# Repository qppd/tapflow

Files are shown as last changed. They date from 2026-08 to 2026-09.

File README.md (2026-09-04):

# TapFlow — RFID-Based Automatic Water and Electrical Line Control with Water Flow Anomaly Detection

> **A Research Project** — Smart water monitoring system that detects leaks and per-room consumption using ESP32 mesh (ESP-NOW), RFID usage tracking, centralized solenoid valve control, and a Next.js web dashboard on Vercel with Firebase Realtime Database + Authentication.

---

## System Overview

```
Room 1 ESP32 ──┐
Room 2 ESP32 ──┼── ESP-NOW ──▶ Main ESP32 ──WiFi──▶ Firebase RTDB
Room 3 ESP32 ──┘            (centralized)              │
     │                      ├── 2× Relay + Solenoid    ▼
     ├── RFID Reader        ├── Calibrated Flow Sensor  Next.js on Vercel
     └── Flow Sensor        │   (GPIO 34)               (Web Dashboard)
       (leak detection)     └── WiFi to Firebase
```

- **3 Room ESP32s** — each has RFID reader (MFRC522) and flow sensor (YF-S201, uncalibrated, leak detection only). Sends readings via ESP-NOW.
- **1 Main ESP32 (centralized)** — receives ESP-NOW data from all rooms, controls 2 solenoid valves via relays, reads calibrated flow sensor (GPIO 34), pushes to Firebase RTDB via WiFi using [mobizt Firebase-ESP-Client](https://github.com/mobizt/Firebase-ESP-Client). Placed before the rooms for centralized control.
- **Firebase** — Realtime Database (data storage) + Authentication (user login)
- **Next.js on Vercel** — web dashboard, real-time monitoring, leak alerts, usage logging per person

---

## Developer Quick-Start: Step-by-Step Process

Follow these steps **in order**. Each step links to the detailed guide.

### Phase 1: Prepare (Do First)

| Step | Action | Guide | Est. Time |
|---|---|---|---|
| 1 | **Buy parts** — Order from BOM (Makerlab Electronics on Shopee/Lazada) | [BOM.md](./docs/bom.md) | 1–2 weeks shipping |
| 2 | **Clone project repo** | [setup.md](./docs/setup.md) | 5 min |

> ⚠️ **Do Step 1–2 in parallel.** Hardware shipping takes longest.

---

### Phase 2: Hardware Assembly

| Step | Action | Guide | Est. Time |
|---|---|---|---|
| 3 | **Wire 3× Room ESP32** — Each gets MFRC522 RFID + YF-S201 flow sensor (leak detection) | [block-diagram.md](./docs/block-diagram.md) | 1 hr |
| 4 | **Wire Main ESP32** — 2× relay (solenoid valves) + calibrated flow sensor + WiFi to Firebase | [block-diagram.md](./docs/block-diagram.md) | 1 hr |
| 5 | **Plumbing** — Install sensors in-line with check valves (arrow = flow direction) | [setup.md](./docs/setup.md) | 2–4 hrs |
| 6 | **Enclosure** — Mount ESP32s in IP67 boxes with cable glands | [block-diagram.md](./docs/block-diagram.md) | 1 hr |

---

### Phase 3: ESP32 Firmware

| Step | Action | Guide | Est. Time |
|---|---|---|---|
| 7 | **Install Arduino IDE 2.x** (Windows/macOS/Linux) | [esp32-firmware-complete-guide.md](./docs/esp32-firmware-complete-guide.md) | 15 min |
| 8 | **Add ESP32 board support** — Board Manager URL + install `esp32 by Espressif Systems` | [esp32-firmware-complete-guide.md](./docs/esp32-firmware-complete-guide.md) | 10 min |
| 9 | **Install libraries** — `ArduinoJson` (JSON) + `MFRC522` (RFID) + `Firebase-ESP-Client` by mobizt + ESP-NOW (built-in) | [esp32-firmware-complete-guide.md](./docs/esp32-firmware-complete-guide.md) | 5 min |
| 10 | **Configure `config.h`** — Device ID, room number, sensor pin, PPL calibration, peer MAC | [esp32-firmware-complete-guide.md](./docs/esp32-firmware-complete-guide.md) | 10 min |
| 11 | **Upload room firmware** to all 3 room ESP32s | [esp32-firmware-complete-guide.md](./docs/esp32-firmware-complete-guide.md) | 5 min |
| 12 | **Upload main firmware** to main ESP32 | [esp32-firmware-complete-guide.md](./docs/esp32-firmware-complete-guide.md) | 5 min |
| 13 | **Verify** — Serial Monitor (921600): room ESP32s send data, main ESP32 receives via ESP-NOW | [esp32-firmware-complete-guide.md](./docs/esp32-firmware-complete-guide.md) | 5 min |

---

### Phase 4: Sensor Calibration

| Step | Action | Guide | Est. Time |
|---|---|---|---|
| 14 | **Bucket test each sensor** — 5L measured, calculate PPL, update `config.h` | [esp32-firmware-complete-guide.md](./docs/esp32-firmware-complete-guide.md#sensor-calibration-bucket-test) | 30 min/sensor |

> 🎯 Target: < 3% error per sensor. Uncalibrated sensors = false leaks / missed leaks.

---

### Phase 5: Web Dashboard (Next.js + Firebase)

| Step | Action | Guide | Est. Time |
|---|---|---|---|
| 15 | **Create Firebase project** — Enable RTDB + Authentication | [setup.md](./docs/setup.md) | 10 min |
| 16 | **Configure Main ESP32** — Add Firebase API key + DB URL to `config.h` | [esp32-firmware-complete-guide.md](./docs/esp32-firmware-complete-guide.md) | 5 min |
| 17 | **Deploy Next.js app** — `vercel deploy`, connect to Firebase | [setup.md](./docs/setup.md) | 10 min |
| 18 | **Power on Main ESP32** — Connects to WiFi → Firebase automatically | — | 2 min |

---

## Essential Guides Only (Bookmark These)

| Guide | Purpose |
|---|---|
| [BOM.md](./docs/bom.md) | Parts list with Shopee links, prices |
| [block-diagram.md](./docs/block-diagram.md) | Pinout, wiring, ESP-NOW topology, enclosure layout |
| [setup.md](./docs/setup.md) | Full phased walkthrough (reference) |
| [esp32-firmware-complete-guide.md](./docs/esp32-firmware-complete-guide.md) | **Complete ESP32 firmware** (room + main, ESP-NOW, ArduinoJson, relay control) |
| [troubleshooting.md](./docs/troubleshooting.md) | Serial commands, LED codes, common fixes |
| [anomaly-detection-guide.md](./docs/anomaly-detection-guide.md) | **Anomaly detection** — algorithms, ESP32 modules, Firebase structure |
| [leak-detection-advanced-guide.md](./docs/leak-detection-advanced-guide.md) | **Leak detection** — 6 rules + mass balance + pulse analysis |
| [module-integration-guide.md](./docs/module-integration-guide.md) | **Module integration** — how all ESP32 modules wire together |
| [web-dashboard-alerts-guide.md](./docs/web-dashboard-alerts-guide.md) | **Web dashboard** — Next.js UI for anomaly/leak detection |

---

### Phase 6: Anomaly + Leak Detection System

| Step | Action | Guide | Est. Time |
|---|---|---|---|
| 19 | **Implement anomaly detection** — Rate-of-change, baseline deviation, burst detection on room ESP32s | [anomaly-detection-guide.md](./docs/anomaly-detection-guide.md) | 2 hrs |
| 20 | **Implement leak detection** — 6 core rules + mass balance + post-shutoff verification | [leak-detection-advanced-guide.md](./docs/leak-detection-advanced-guide.md) | 2 hrs |
| 21 | **Integrate modules** — Wire detection modules into ESP32 main loops, ESP-NOW payload, Firebase push | [module-integration-guide.md](./docs/module-integration-guide.md) | 2 hrs |
| 22 | **Build dashboard alerts** — Real-time alert feed, severity badges, threshold config, trend charts | [web-dashboard-alerts-guide.md](./docs/web-dashboard-alerts-guide.md) | 3 hrs |
| 23 | **Validate** — Test all 6 leak rules, anomaly detection, false positive reduction, Firebase sync | All detection guides | 2 hrs |

> **Detection order:** anomaly-detection-guide → leak-detection-advanced-guide → module-integration-guide → web-dashboard-alerts-guide

---

## Hardware Summary

| Component | Qty | Key Spec |
|---|-----|---|
| ESP32 38-pin Dev Module | 4 | 3 room + 1 main, CP2102/CH340 USB-UART |
| ESP32 Expansion Board | 4 | Screw terminals for each ESP32 |
| MFRC522 RFID Reader | 3 | SPI, 1 per room — usage tracking |
| RFID Cards/Tags | 3+ | Mifare Classic 1K — one per user |
| YF-S201 Flow Sensor | 4 | 3 rooms (leak detection, uncalibrated) + 1 main (calibrated) |
| 2CH Relay with Optocoupler | 1 | Main ESP32 controls 2 solenoids |
| 1-ch Relay 10A | 3 | 1 per room — controls solenoid valve |
| Fotek 40A SSR | 3 | 1 per room — controls room power (lights/fan) |
| Solenoid Valve 1/2" | 5 | NC (normally closed), 12V DC, 2 main + 3 room |
| Check Valve 1/2" | 3 | Brass, prevent backflow |
| PPE Pipe + Fittings | 1 set | 1/2" Polypropylene, heat-fused joints |
| 12V 5A PSU + LM2596S buck | 4 | 220V → 12V → 5V, 1 per ESP32 |
| DC Power Jack Adapter | 4 | 5.5×2.1mm, connects PSU to expansion board |
| IP67 ABS Enclosure | 4 | 175×125×75mm, one per ESP32 |

---

## 3D Models

Fusion 360 source files and fixture renders are in the [`models/`](./models/) folder:

| File | Description |
|---|---|
| [`TapFlow.f3d`](./models/TapFlow.f3d) | Fusion 360 source file (editable) |
| [`tapflow_view_1.png`](./models/tapflow_view_1.png) | Fixture view 1 |
| [`tapflow_view_2.png`](./models/tapflow_view_2.png) | Fixture view 2 |
| [`tapflow_view_3.png`](./models/tapflow_view_3.png) | Fixture view 3 |
| [`tapflow_view_4.png`](./models/tapflow_view_4.png) | Fixture view 4 |
| [`tapflow_view_5.png`](./models/tapflow_view_5.png) | Fixture view 5 |
| [`tapflow_view_6.png`](./models/tapflow_view_6.png) | Fixture view 6 |
| [`tapflow_view_7.png`](./models/tapflow_view_7.png) | Fixture view 7 |
| [`tapflow_view_8.png`](./models/tapflow_view_8.png) | Fixture view 8 |

> Open `TapFlow.f3d` in Fusion 360 to modify the enclosure design, add mounting holes, or adjust dimensions for different components.

---

## Quick Verification Checklist

After each phase, verify:

- [ ] **Phase 1:** All parts received, repo cloned
- [ ] **Phase 2:** All 3 room ESP32s powered, RFID reads cards, sensors pulse; main ESP32 triggers solenoids via relay
- [ ] **Phase 3:** ESP-NOW link working — room data + RFID tags appear on main ESP32 Serial Monitor
- [ ] **Phase 4:** 5L bucket test → < 3% error on each sensor
- [ ] **Phase 5:** Main ESP32 connected to WiFi, data visible in Firebase RTDB, Next.js dashboard shows live data
- [ ] **Phase 6:** All 6 leak rules trigger correctly, anomaly detection working, dashboard shows real-time alerts

---

## License

MIT

## Author

[qppd](https://github.com/qppd) — Quezon Province, Philippines

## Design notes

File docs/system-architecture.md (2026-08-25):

# System Architecture — TapFlow

## Overview

Smart water monitoring system with **per-room leak detection** using **ESP32 mesh (ESP-NOW) → Main ESP32 → WiFi → Firebase → Next.js on Vercel**.

3 room ESP32s each have an **MFRC522 RFID reader** (usage tracking), a **YF-S201 flow sensor** (leak detection, uncalibrated), a **Fotek 40A SSR** (room power), and a **1-ch relay driving a room-local solenoid valve**. Room ESP32s transmit readings wirelessly via **ESP-NOW** to a centralized main ESP32. The main ESP32 controls **2 centralized solenoid valves via 2CH relay**, reads a **calibrated flow sensor** (accurate metering), and connects to WiFi to push data directly to **Firebase Realtime Database** using the [mobizt Firebase-ESP-Client](https://github.com/mobizt/Firebase-ESP-Client) library. It also receives commands and callbacks from Firebase. The web dashboard is a **Next.js app deployed on Vercel** with **Firebase Authentication** for user login.

---

## Waterline Structure (Plumbing)

```
Water Tank (500-1000L)
    │
    ▼
Fittings → 1" Pipe
    │
    ▼
Reducer Fittings (1" → 1/2")
    │
    ▼
Solenoid Valve 1 (12V NC) ◄── 2CH Relay IN1 (GPIO 19)
    │
    ▼
Flow Sensor (calibrated) ◄── GPIO 34
    │
    ▼
Solenoid Valve 2 (12V NC) ◄── 2CH Relay IN2 (GPIO 18)
    │
    ▼
T-Connector → 1/2" PPE Pipe → Each Room
    ├──→ Room 1 (Bathroom)
    ├──→ Room 2 (Kitchen)
    └──→ Room 3 (Shower)
```

> **Dual Solenoid Design:** Two solenoid valves in series for redundancy — if one fails stuck open, the other can still shut off water. Flow sensor placed between solenoids for accurate metering of total household consumption.

---

## Architecture Diagram

> Mermaid-based diagram (SVG export removed; source below)

<details>
<summary><b> Mermaid Source</b> (click to expand)</summary>

```mermaid
graph TB
    subgraph "Room 1 — Bathroom"
        RFID1[MFRC522 RFID<br/>Usage Tracking] --> R1[Room ESP32 #1]
        R1S["Flow Sensor<br/>YF-S201 (leak)"] --> R1
        R1 --> SSR1[Fotek 40A SSR<br/>Room Power]
        SSR1 --> LIGHTS1[Lights/Fan/Appliances]
        R1 --> RELAY1[1-ch Relay<br/>Solenoid]
        RELAY1 --> SOL1[Solenoid Valve<br/>12V NC]
        R1 --> R1E[ESP-NOW Transmitter]
    end

    subgraph "Room 2 — Kitchen"
        RFID2[MFRC522 RFID<br/>Usage Tracking] --> R2[Room ESP32 #2]
        R2S["Flow Sensor<br/>YF-S201 (leak)"] --> R2
        R2 --> SSR2[Fotek 40A SSR<br/>Room Power]
        SSR2 --> LIGHTS2[Lights/Fan/Appliances]
        R2 --> RELAY2[1-ch Relay<br/>Solenoid]
        RELAY2 --> SOL2[Solenoid Valve<br/>12V NC]
        R2 --> R2E[ESP-NOW Transmitter]
    end

    subgraph "Room 3 — Shower"
        RFID3[MFRC522 RFID<br/>Usage Tracking] --> R3[Room ESP32 #3]
        R3S["Flow Sensor<br/>YF-S201 (leak)"] --> R3
        R3 --> SSR3[Fotek 40A SSR<br/>Room Power]
        SSR3 --> LIGHTS3[Lights/Fan/Appliances]
        R3 --> RELAY3[1-ch Relay<br/>Solenoid]
        RELAY3 --> SOL3[Solenoid Valve<br/>12V NC]
        R3 --> R3E[ESP-NOW Transmitter]
    end

    subgraph "Main ESP32 — Centralized"
        direction TB
        ESPRX[ESP-NOW Receiver<br/>Aggregates Room Data]
        MFS["Calibrated Flow Sensor<br/>YF-S201 (GPIO 34)"] --> MAIN[Main ESP32]
        ESPRX --> MAIN
        MAIN --> RELAY12[2CH Relay<br/>IN1→GPIO 19, IN2→GPIO 18]
        RELAY12 --> MSOL1[Solenoid Valve 1<br/>12V NC]
        RELAY12 --> MSOL2[Solenoid Valve 2<br/>12V NC]
        MAIN --> WIFI[WiFi + mobizt<br/>Firebase-ESP-Client]
    end

    subgraph "Firebase Cloud"
        RTDB[(Firebase Realtime<br/>Database)]
        Auth[Firebase Authentication<br/>User Login]
    end

    subgraph "Vercel"
        NextJS[Next.js App<br/>Web Dashboard]
    end

    R1E -.->|ESP-NOW| ESPRX
    R2E -.->|ESP-NOW| ESPRX
    R3E -.->|ESP-NOW| ESPRX
    WIFI -.->|WiFi + mobizt SDK| RTDB
    RTDB --> NextJS
    Auth --> NextJS
```

</details>

---

## Data Flow (End-to-End)

```
Step 1: RFID TAP (per room)
        Customer taps Mifare card on MFRC522 reader
        → Validate card against registered cards for this room
        → Send RFID event via ESP-NOW to main ESP32
        → Log RFID tag + timestamp to SPIFFS / send via ESP-NOW

Step 2: LEAK DETECTION (per room)
        Room flow sensor monitors for leaks (uncalibrated):
        → Flow detected when no RFID session = leak alert
        → Send leak_alert via ESP-NOW to main ESP32

Step 3: CENTRALIZED SOLENOID CONTROL (main ESP32)
        Main ESP32 receives ESP-NOW data from rooms:
        → Validates RFID session + checks leak alerts
        → Controls the 2 centralized solenoid valves via 2CH relay (GPIO HIGH/LOW)
        → (Each room also drives its own local solenoid via its 1-ch relay)
        → Reads calibrated flow sensor for accurate metering
        → Smart auto on/off prevents overheating

Step 4: ESP-NOW TRANSMISSION (every 5 sec)
        Room ESP32 → Main ESP32 (broadcast)
        → Payload: {room_id, rfid_tag, pulses, leak_alert}

Step 5: MAIN ESP32 → FIREBASE (WiFi + mobizt)
        Main ESP32 receives from all 3 rooms via ESP-NOW:
        → Aggregate room data into Firebase JSON structure
        → Push to Firebase RTDB using mobizt Firebase-ESP-Client
        → Path: /rooms/{room_id}/data, /rooms/{room_id}/alerts
        → Also reads commands from Firebase (remote shutoff, config updates)

Step 6: FIREBASE CLOUD
        → Realtime Database stores all room data, usage logs, alerts
        → Firebase Authentication handles user login (email/password or Google)
        → Real-time sync to all connected clients
        → ESP32 receives callbacks for remote commands

Step 7: USER ACTION (Next.js on Vercel)
        → User logs in via Firebase Auth
        → Dashboard displays real-time readings per room (Firebase RTDB listener)
        → Usage logs per person (RFID tag + duration + volume)
        → Leak alerts appear instantly (real-time sync)
        → User can send remote commands (shutoff, config) via Firebase → ESP32
```

---

## Communication Paths

| Path | Method | Protocol | Library |
|---|---|---|---|
| RFID Card → Room ESP32 | SPI (MFRC522) | Mifare Classic | MFRC522 library |
| Flow Sensor → Room ESP32 | Pulse (GPIO interrupt) | Rising edge | Arduino ISR |
| Main ESP32 → Relay → Solenoid | GPIO HIGH/LOW | Digital signal | Arduino digitalWrite |
| Room ESP32 → Main ESP32 | ESP-NOW (wireless) | Binary payload | esp_now.h (built-in) |
| Main ESP32 → Firebase | WiFi + HTTPS | JSON (RTDB) | mobizt Firebase-ESP-Client |
| Firebase → Main ESP32 | WiFi + HTTPS | Callbacks/Streams | mobizt Firebase-ESP-Client |
| Firebase → Next.js | WebSocket (RTDB) | Real-time sync | Firebase JS SDK |
| User → Dashboard | HTTPS | Internet | Next.js + Firebase Auth |
| Dashboard → ESP32 | Firebase RTDB | Remote commands | mobizt stream + set |

---

## Key Design Decisions

| Decision | Rationale |
|---|---|
| **ESP-NOW for room-to-main** | Low-latency, no WiFi router needed, works offline, peer-to-peer |
| **mobizt Firebase-ESP-Client** | Direct ESP32 → Firebase, stream + callback support |
| **WiFi on main ESP32 only** | Room ESP32s stay offline (ESP-NOW only) — saves power, no WiFi config per room |
| **Dual-layer solenoid control** | Main ESP32 controls the 2 centralized valves via 2CH relay; each room also drives its own solenoid via a 1-ch relay |
| **RFID per room** | MFRC522 tracks who used water (tap card to log usage) |
| **Firebase RTDB** | Real-time sync, ESP32 reads/writes directly, no backend server needed |
| **Firebase Auth** | User login (email/password, Google sign-in) — no custom auth system |
| **Next.js on Vercel** | Serverless, auto-deploy from Git, free tier sufficient |
| **6 Leak Detection Rules** | No RFID+flow, session ended+flow, solenoid OFF+flow, continuous flow, drip, night flow |
| **RFID-based leak context** | RFID session state tells firmware whether flow is expected or a leak |
| **Check Valves per Room** | Prevents backflow contamination between rooms |
| **SPIFFS Backup** | Survives WiFi disconnects — data cached locally until reconnect |
| **921600 baud** | High throughput for 3 rooms × 5 sec interval; reliable on CP2102/CH340 |

---

## Hardware Summary

| Component | Qty | Purpose |
|---|-----|---|
| ESP32 38-Pin Dev Board | 4 | 3 room + 1 main |
| ESP32 38-Pin Expansion Board | 4 | Screw terminals for wiring |
| MFRC522 RFID Reader | 3 | 1 per room — usage tracking |
| YF-S201 Flow Sensor | 4 | 3 rooms (leak detection, uncalibrated) + 1 main (calibrated) |
| 2CH Relay with Optocoupler | 1 | Main ESP32 — controls 2 centralized solenoid valves |
| 1-ch Relay 10A | 3 | 1 per room — controls the room solenoid valve |
| Fotek 40A SSR | 3 | 1 per room — room power (lights/fan/appliances) |
| Solenoid Valve 1/2" NC | 5 | 12V DC, normally closed — 2 central (main) + 3 room |
| Check Valve 1/2" | 3 | One per room line (backflow prevention) |
| 12V 5A Switching PSU (S-60-12 / LRS-60-12) | 4 | 1 per ESP32 — Mains power → 12V |
| LM2596S Buck Converter | 4 | 1 per ESP32 — 12V → 5V |
| Waterproof ABS Enclosure IP67 (175×125×75mm) | 4 | One per ESP32 |

---

## Power Architecture

```
Per-ESP32 Power (×4 — each has its own PSU + buck):

220V AC Outlet
    │
    ▼
12V 5A Switching PSU (S-60-12 / LRS-60-12)
    │
    ├──► 12V Rail → Solenoid Valves (main ESP32 only)
    │
    ▼
LM2596S Buck Converter (12V → 5V)
    │
    ├──► ESP32 VIN (5V)
    ├──► Flow Sensor VCC (5V)
    └──► RFID / other 5V sensors
```

> **Room ESP32s** connect to: MFRC522 RFID (SPI, RST→GPIO 21), YF-S201 flow sensor (GPIO 26), Fotek 40A SSR (GPIO 27, room power), and 1-ch relay (GPIO 25, solenoid). **Main ESP32** connects to: calibrated YF-S201 flow sensor (GPIO 34), 2CH relay (IN1→GPIO 19, IN2→GPIO 18) for solenoid valves, reset button (GPIO 27), and WiFi. Main ESP32 is centralized before the rooms — controls both solenoid valves via 2CH relay and reads calibrated flow sensor.

---

## References

- [ESP32 Arduino Core Documentation](https://docs.espressif.com/projects/arduino-esp32/en/latest/)
- [Firebase-ESP-Client (mobizt)](https://github.com/mobizt/Firebase-ESP-Client)
- [Next.js Documentation](https://nextjs.org/docs)

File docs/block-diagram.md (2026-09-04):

# Block Diagram — TapFlow (ESP-NOW + WiFi → Firebase)

## System Block Diagram

> Mermaid-based diagram (SVG export removed; source below)

<details>
<summary><b> Mermaid Source</b> (click to expand)</summary>

```mermaid
graph TB
    subgraph "Room 1 — Bathroom"
        RFID1[MFRC522 RFID] --> R1[Room ESP32 #1]
        R1S["Flow Sensor YF-S201\n(leak detection)"] --> R1
        R1 --> SSR1[Fotek 40A SSR\nRoom Power]
        R1 --> RRLY1[1-ch Relay\nRoom Solenoid]
        RRLY1 --> RSOL1[Solenoid Valve\n12V NC]
        R1 --> R1E[ESP-NOW TX]
    end

    subgraph "Room 2 — Kitchen"
        RFID2[MFRC522 RFID] --> R2[Room ESP32 #2]
        R2S["Flow Sensor YF-S201\n(leak detection)"] --> R2
        R2 --> SSR2[Fotek 40A SSR\nRoom Power]
        R2 --> RRLY2[1-ch Relay\nRoom Solenoid]
        RRLY2 --> RSOL2[Solenoid Valve\n12V NC]
        R2 --> R2E[ESP-NOW TX]
    end

    subgraph "Room 3 — Shower"
        RFID3[MFRC522 RFID] --> R3[Room ESP32 #3]
        R3S["Flow Sensor YF-S201\n(leak detection)"] --> R3
        R3 --> SSR3[Fotek 40A SSR\nRoom Power]
        R3 --> RRLY3[1-ch Relay\nRoom Solenoid]
        RRLY3 --> RSOL3[Solenoid Valve\n12V NC]
        R3 --> R3E[ESP-NOW TX]
    end

    subgraph "Main ESP32 — Centralized"
        ESPRX[ESP-NOW RX Aggregator] --> MAIN[Main ESP32]
        MFS["Flow Sensor\n(calibrated, GPIO 34)"] --> MAIN
        MAIN --> RELAY12[2CH Relay\nIN1→GPIO 19, IN2→GPIO 18]
        RELAY12 --> SOL1[Solenoid Valve 1\n12V NC]
        RELAY12 --> SOL2[Solenoid Valve 2\n12V NC]
        MAIN --> WIFI[WiFi + mobizt SDK]
    end

    subgraph "Firebase Cloud"
        RTDB[(Firebase Realtime DB)]
        AUTH[Firebase Auth]
    end

    subgraph "Vercel"
        NEXT[Next.js Dashboard]
    end

    WIFI -.->|WiFi + mobizt| RTDB
    RTDB --> NEXT
    AUTH --> NEXT

    R1E -.->|ESP-NOW| ESPRX
    R2E -.->|ESP-NOW| ESPRX
    R3E -.->|ESP-NOW| ESPRX
```

</details>

---

## Waterline Structure (Plumbing)

```
Water Tank (500-1000L)
    │
    ▼
Fittings → 1" Pipe
    │
    ▼
Reducer Fittings (1" → 1/2")
    │
    ▼
╔═══════════════════════════════════════════════════╗
║  MAIN ESP32 CONTROL ZONE                          ║
║                                                   ║
║  Solenoid Valve 1 (12V NC) ◄── 2CH Relay IN1     ║
║       │                                           ║
║       ▼                                           ║
║  Flow Sensor (calibrated) ◄── GPIO 34            ║
║       │                                           ║
║       ▼                                           ║
║  Solenoid Valve 2 (12V NC) ◄── 2CH Relay IN2     ║
╚═══════════════════════════════════════════════════╝
    │
    ▼
T-Connector → 1/2" PPE Pipe
    │
    ├──→ Room 1 (Bathroom)
    ├──→ Room 2 (Kitchen)
    └──→ Room 3 (Shower)
```

> **Dual Solenoid Design:** Two solenoid valves in series for redundancy — if one fails stuck open, the other can still shut off water. Flow sensor placed between solenoids for accurate metering of total household consumption.

---

## Pin Connections

### Room ESP32s (×3) — RFID + flow sensor + SSR + relay + solenoid

| Component | Interface | Pins | Notes |
|---|---|---|---|
| **MFRC522 RFID** | SPI | SDA→GPIO 5, SCK→GPIO 18, MOSI→GPIO 23, MISO→GPIO 19, RST→GPIO 21 | Reads Mifare Classic cards |
| **YF-S201 Flow Sensor** | Digital | GPIO 26 | Leak detection only (uncalibrated) |
| **Fotek 40A SSR** | Digital | GPIO 27 | Room power — controls lights, fan, appliances |
| **1-ch Relay 10A** | Digital | GPIO 25 | Solenoid valve control |
| **Built-in LED** | Digital | GPIO 2 | Status indication |
| **Power** | 12V jack | 6.5–16V input | Expansion board accepts 12V from switching PSU |

### Main ESP32 — Centralized Control (WiFi + 2CH relay + solenoids + calibrated flow sensor)

| Component | Interface | Pins | Notes |
|---|---|---|---|
| **YF-S201 Flow Sensor** | Digital | GPIO 34 | Calibrated — accurate metering |
| **2CH Relay (Solenoid 1)** | Digital | GPIO 19 | HIGH = water flows, LOW = shutoff |
| **2CH Relay (Solenoid 2)** | Digital | GPIO 18 | HIGH = water flows, LOW = shutoff |
| **Solenoid Valve ×2** | Via 2CH relay | 12V NC | COM→solenoid+, NO→PSU+, solenoid-→PSU- |
| **Reset Button** | Digital | GPIO 27 | Arcade button — press to reset WiFi creds |
| **WiFi** | WiFi + mobizt SDK | — | Connects to Firebase RTDB |
| **ESP-NOW RX** | ESP-NOW | — | Receives RFID + leak alerts from room ESP32s |
| **Built-in LED** | Digital | GPIO 2 | Status indication |
| **Power** | 12V jack | 6.5–16V input | Expansion board accepts 12V from switching PSU |

---

## Wiring Diagram

### Interactive Wiring Diagram (Cirkit Designer)
**🔗 [View Interactive Wiring Diagram](https://app.cirkitdesigner.com/project/b0b4579e-313d-4faa-9cd1-f955daa204a5)**

### Static Wiring Diagram (PNG)
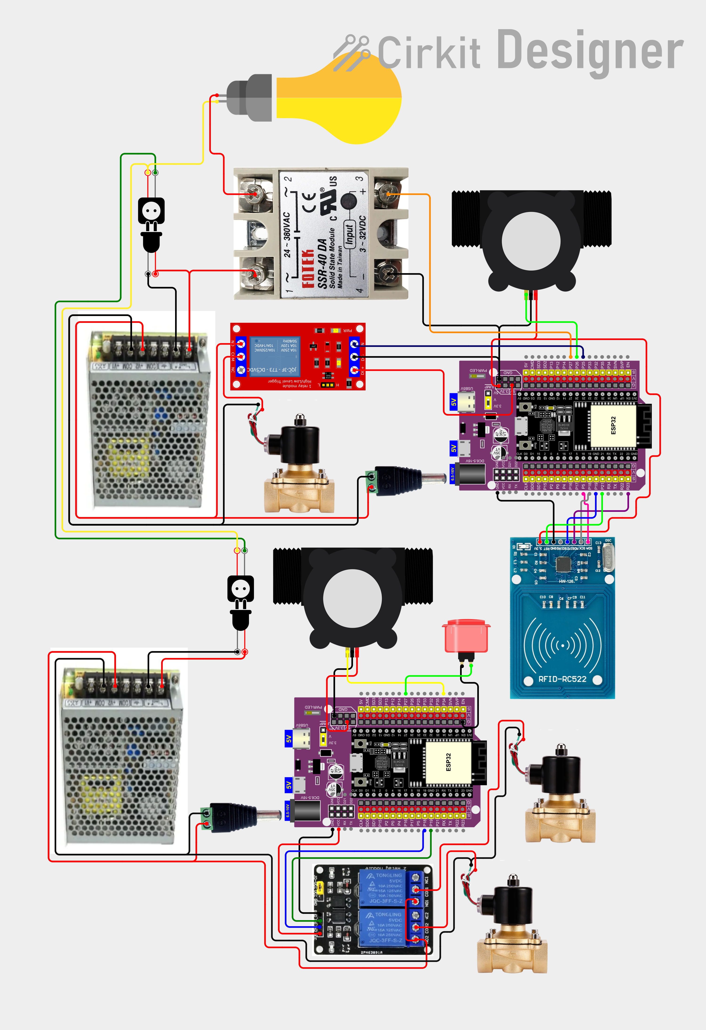
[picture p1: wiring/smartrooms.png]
Wiring Diagram


---

## Simplified Wiring

### Room ESP32 (×3 — same wiring each)
```
Room ESP32 38-Pin Expansion Board
┌─────────────────────────────────────────────────────┐
│                                                     │
│  SPI Bus (MFRC522 RFID):                           │
│  [5]  ──────┬── MFRC522 SDA (NSS)                  │
│  [18] ──────┬── MFRC522 SCK                        │
│  [23] ──────┬── MFRC522 MOSI                       │
│  [19] ──────┬── MFRC522 MISO                       │
│  [21] ──────┬── MFRC522 RST                        │
│  3V   ──────┬── MFRC522 3.3V                       │
│  GND  ──────┬── MFRC522 GND                        │
│                                                     │
│  Flow Sensor (leak detection — uncalibrated):      │
│  [26] ──────┬── YF-S201 Signal (Yellow)            │
│  5V   ──────┬── YF-S201 VCC (Red)                  │
│  GND  ──────┬── YF-S201 GND (Black)                │
│                                                     │
│  SSR (Room Power — lights, fan, appliances):       │
│  [27] ──────┬── Fotek 40A SSR Input +              │
│  GND  ──────┬── Fotek 40A SSR Input -              │
│  SSR OUT1 ──┬── 220V line                          │
│  SSR OUT2 ──┬── Appliance 1st wire                 │
│  Appliance 2nd wire ── 220V line                   │
│                                                     │
│  Relay (Solenoid Valve):                           │
│  [25] ──────┬── 1-ch Relay IN                      │
│  5V   ──────┬── Relay VCC                          │
│  GND  ──────┬── Relay GND                          │
│  Relay COM ──┬── Solenoid +                        │
│  Relay NO  ──┬── PSU + (12V)                       │
│  Solenoid - ── PSU - (directly)                    │
│                                                     │
│  Power: 12V jack input (6.5–16V from PSU)          │
└─────────────────────────────────────────────────────┘
```

### Main ESP32 — Centralized Control
```
Main ESP32 38-Pin Expansion Board
┌─────────────────────────────────────────────────────┐
│                                                     │
│  Flow Sensor (calibrated — accurate metering):     │
│  [34] ──────┬── YF-S201 Signal (Yellow)            │
│  5V   ──────┬── YF-S201 VCC (Red)                  │
│  GND  ──────┬── YF-S201 GND (Black)                │
│                                                     │
│  2CH Relay (Solenoid Valves 1 & 2):                │
│  5V   ──────┬── Relay VCC                           │
│  GND  ──────┬── Relay GND                           │
│  [19] ──────┬── Relay IN1 (Solenoid 1)              │
│  [18] ──────┬── Relay IN2 (Solenoid 2)              │
│  COM1 ──────┬── Solenoid 1 +                        │
│  COM2 ──────┬── Solenoid 2 +                        │
│  NO1  ──────┬── PSU + (12V)                         │
│  NO2  ──────┬── PSU + (12V)                         │
│  Solenoid 1- ── PSU - (directly)                    │
│  Solenoid 2- ── PSU - (directly)                    │
│                                                     │
│  Reset Button (WiFi creds reset):                  │
│  [27] ──────┬── Arcade Button Pin 2                 │
│  GND  ──────┬── Arcade Button Pin 1                 │
│                                                     │
│  WiFi + ESP-NOW RX (receives from room ESP32s)     │
│  [2]  ──────┬── Built-in LED (status)               │
│                                                     │
│  Power: 12V jack input (6.5–16V from PSU)          │
└─────────────────────────────────────────────────────┘
```
> Main ESP32 is centralized before the rooms. It controls both solenoid valves via 2CH relay and reads the calibrated flow sensor. Room ESP32s report RFID taps and leak alerts wirelessly via ESP-NOW. Arcade button on GPIO 27 allows resetting WiFi credentials.

---

## Smart Solenoid Control Flow (per Room)

```
┌─────────────────────────────────────────────────────────────────┐
│                     RFID TAP VALID                               │
│                                                                 │
│  Customer taps card  ──▶  MFRC522 reads  ──▶  Validate card     │
│                                                      │          │
│                                              ┌───────┴───────┐  │
│                                              │  Valid card?   │  │
│                                              └───────┬───────┘  │
│                                                  YES │          │
│                                                      ▼          │
│                                              SSR ON + Solenoid ON│
│                                              (water flows)       │
└─────────────────────────────────────────────────────────────────┘

┌─────────────────────────────────────────────────────────────────┐
│                   SMART SOLENOID CONTROL                         │
│                                                                 │
│  Flow sensor active? ──▶ YES ──▶ Solenoid stays ON              │
│         │                                                     │
│         NO (no flow for N sec)                                │
│         │                                                     │
│         ▼                                                     │
│  Solenoid OFF automatically (prevents overheating)             │
│         │                                                     │
│         ▼                                                     │
│  Next flow detected? ──▶ YES ──▶ Solenoid ON again             │
└─────────────────────────────────────────────────────────────────┘

┌─────────────────────────────────────────────────────────────────┐
│                      SESSION END                                │
│                                                                 │
│  Timeout (no flow X min) ──▶ SSR OFF (room power off)           │
│  Tap card again           ──▶ SSR OFF (session ends)            │
│  Leak detected            ──▶ SSR OFF + Solenoid OFF (emergency)│
└─────────────────────────────────────────────────────────────────┘
```

> **Key principle:** Solenoid is ONLY energized when water is actually flowing. This prevents the solenoid from overheating due to continuous energization.

---

## Leak Detection Scenarios (6 Rules)

```
┌─────────────────────────────────────────────────────────────────┐
│  RULE 1: NO RFID + FLOW DETECTED           → CRITICAL LEAK     │
│  ─────────────────────────────────────────────────────────────  │
│  No customer in room (no session) but flow sensor reads water.  │
│  Cause: Broken pipe, burst fitting, upstream valve failure.     │
│  Action: EMERGENCY SHUTOFF + ALERT                              │
└─────────────────────────────────────────────────────────────────┘

┌─────────────────────────────────────────────────────────────────┐
│  RULE 2: SESSION ENDED + FLOW CONTINUES   → SOLENOID STUCK     │
│  ─────────────────────────────────────────────────────────────  │
│  Customer left (SSR OFF) but water still flowing.              │
│  Cause: Solenoid valve physically stuck open.                   │
│  Action: EMERGENCY SHUTOFF + ALERT + CHECK SOLENOID HARDWARE   │
└─────────────────────────────────────────────────────────────────┘

┌─────────────────────────────────────────────────────────────────┐
│  RULE 3: SOLENOID OFF + FLOW DETECTED     → HARDWARE FAILURE   │
│  ─────────────────────────────────────────────────────────────  │
│  Valve commanded closed but flow sensor still reads water.     │
│  Cause: Solenoid stuck, SSR welded contacts, pipe burst.       │
│  Action: EMERGENCY SHUTOFF + ALERT + CHECK SSR + SOLENOID      │
└─────────────────────────────────────────────────────────────────┘

┌─────────────────────────────────────────────────────────────────┐
│  RULE 4: CONTINUOUS FLOW > 30 MIN          → STUCK VALVE       │
│  ─────────────────────────────────────────────────────────────  │
│  Water flowing non-stop for 30+ minutes.                        │
│  Cause: Stuck valve, running toilet, forgotten faucet.         │
│  Action: EMERGENCY SHUTOFF + ALERT                              │
└─────────────────────────────────────────────────────────────────┘

┌─────────────────────────────────────────────────────────────────┐
│  RULE 5: DRIP (0.1–0.5 L/min) > 5 MIN     → DRIP LEAK          │
│  ─────────────────────────────────────────────────────────────  │
│  Slow, steady trickle for extended time.                        │
│  Cause: Dripping faucet, loose fitting, worn washer.           │
│  Action: EMERGENCY SHUTOFF + ALERT                              │
└─────────────────────────────────────────────────────────────────┘

┌─────────────────────────────────────────────────────────────────┐
│  RULE 6: NIGHT FLOW (22:00–05:00) NO SESSION → SUSPICIOUS      │
│  ─────────────────────────────────────────────────────────────  │
│  Water flowing during sleeping hours with no authorized user.   │
│  Cause: Unauthorized use, hidden leak, pipe burst at night.    │
│  Action: EMERGENCY SHUTOFF + ALERT                              │
└─────────────────────────────────────────────────────────────────┘
```

> **All 6 rules trigger the same emergency response:**
> 1. SSR OFF (room power cut)
> 2. Solenoid OFF (water stopped)
> 3. Alert sent via ESP-NOW → Main ESP32 → Firebase RTDB → Next.js dashboard notification
> 4. Event logged to SPIFFS + Firebase RTDB for audit trail

---

## Sensor Wiring (YF-S201) — per Room ESP32

```
YF-S201 Flow Sensor
┌──────────────┐
│              │
│  Red   ─────┼──── 5V (VIN from Room ESP32)
│  Black ─────┼──── GND
│  Yellow ────┼──── GPIO 26 — direct connection
│              │
│  [Flow →]    │   ← Arrow indicates water flow direction
└──────────────┘
```

> **Important:** The arrow on the sensor body MUST point in the direction of water flow. Installing it backwards will give no readings.

Each YF-S201 sensor has 3 wires: **Red (VCC)**, **Black (GND)**, **Yellow (Signal)**

| Connection | Wire Color | Pin |
|---|---|-----|
| VCC | Red | 5V |
| GND | Black | GND |
| Signal | Yellow | GPIO 26 |

---

## Power Distribution

> Mermaid-based diagram (SVG export removed; source below)

<details>
<summary><b> Mermaid Source</b> (click to expand)</summary>

```mermaid
graph LR
    AC1[220V AC<br/>Outlet] --> PSU1["12V 5A PSU #1<br/>(Room ESP32)"]
    PSU1 --> BUCK1[LM2596S<br/>Buck #1]
    BUCK1 --> ESP1["Room ESP32<br/>(5V)"]
    PSU1 --> SOL1[Solenoid<br/>12V] & SSR1[SSR<br/>12V]

    AC2[220V AC<br/>Outlet] --> PSU2["12V 5A PSU #2<br/>(Room ESP32)"]
    PSU2 --> BUCK2[LM2596S<br/>Buck #2]
    BUCK2 --> ESP2["Room ESP32<br/>(5V)"]
    PSU2 --> SOL2[Solenoid<br/>12V] & SSR2[SSR<br/>12V]

    AC3[220V AC<br/>Outlet] --> PSU3["12V 5A PSU #3<br/>(Room ESP32)"]
    PSU3 --> BUCK3[LM2596S<br/>Buck #3]
    BUCK3 --> ESP3["Room ESP32<br/>(5V)"]
    PSU3 --> SOL3[Solenoid<br/>12V] & SSR3[SSR<br/>12V]

    AC4[220V AC<br/>Outlet] --> PSU4["12V 5A PSU #4<br/>(Main ESP32)"]
    PSU4 --> BUCK4[LM2596S<br/>Buck #4]
    BUCK4 --> ESP4["Main ESP32<br/>(5V)"]
```

</details>

> **Power Architecture:**
> - **Each ESP32 has its own dedicated power supply** — no shared rails
> - **220V AC** → **12V 5A Switching PSU (S-60-12)** → **LM2596S Buck Converter** → **5V** for ESP32 + sensors
> - **12V rail** powers solenoid valves and SSR relays directly per room
> - **4 total:** 3 for room ESP32s + 1 for main ESP32
> - Main ESP32 connects to WiFi directly

---

## Component Layout (Enclosure)

> Mermaid-based diagram (SVG export removed; source below)

<details>
<summary><b> Mermaid Source</b> (click to expand)</summary>

```mermaid
graph TD
    Enclosure[Waterproof ABS Enclosure Box<br/>IP67 175x125x75mm<br/>with cable glands for<br/>waterproof sensor cable entry]
```

</details>

> **Enclosure:** Waterproof ABS Enclosure Box IP67 175x125x75mm with cable glands for waterproof sensor cable entry.

---

## Pinout Reference (ESP32 DevKit V1 38-Pin)

```
                   ┌─────────────┐
             EN ──┤ 1         38├── VBAT
           GPIO36─┤ 2         37├── GPIO15 (HSPI_CS)
           GPIO39─┤ 3         36├── GPIO2 (LED)
           GPIO34─┤ 4         35├── GPIO0 (BOOT)
           GPIO35─┤ 5         34├── GPIO4
           GPIO32─┤ 6         33├── GPIO16 (RXD2)
           GPIO33─┤ 7         32├── GPIO17 (TXD2)
           GPIO25─┤ 8         31├── GPIO5
           GPIO26─┤ 9         30├── GPIO18
           GPIO27─┤ 10        29├── GPIO19
           GPIO14─┤ 11        28├── GPIO21
           GPIO12─┤ 12        27├── GPIO22
           GPIO13─┤ 13        26├── GPIO23
              GND─┤ 14        25├── RXD0 (GPIO3)
           GPIO15─┤ 15        24├── TXD0 (GPIO1)
              GND─┤ 16        23├── (NC)
            3.3V ─┤ 17        22├── (NC)
             5V  ─┤ 18        21├── (NC)
              GND─┤ 19        20├── GND
                   └─────────────┘
```

> **Room ESP32 pin usage:** GPIO 26 (flow sensor), GPIO 27 (SSR), GPIO 25 (solenoid relay), GPIO 5/18/19/23 (RFID SPI) + GPIO 21 (RST). Direct connection, no pull-up resistors needed (YF-S201 outputs digital pulses).

---

## ESP-NOW Protocol (Room → Main ESP32)

**Wireless:** ESP-NOW (no WiFi router needed)  
**Payload:** Binary struct (low-latency)

### Room → Main (every 5 sec)
```json
{"room_id": 1, "ts": 1703123456789, "pulses": 127, "flow_rate_lpm": 2.34, "volume_ml": 456, "leak_alert": false}
```

### Main → Room (command, on demand)
```json
{"cmd": "calibrate", "ppl": 450}
{"cmd": "reset_counters"}
```

---

## Firebase RTDB Structure (Main ESP32 → Firebase)

**Format:** JSON Lines (newline-delimited JSON)  
**Encoding:** UTF-8

### Aggregated Data Frame (every 5 sec)
```json
{"device_id": "tapflow-main", "ts": 1703123456789, "rooms": [{"room_id": 1, "flow_rate_lpm": 2.34, "volume_ml": 456}, {"room_id": 2, "flow_rate_lpm": 0.0, "volume_ml": 0}, {"room_id": 3, "flow_rate_lpm": 1.12, "volume_ml": 210}]}
```

### Alert Frame (leak detected)
```json
{"device_id": "tapflow-main", "ts": 1703123456789, "type": "alert", "level": "major_leak", "room_id": 2, "flow_rate_lpm": 15.2, "duration_sec": 45, "message": "Major leak detected in Kitchen"}
```

### Command Frame (Firebase → Main ESP32 via mobizt stream)
```json
{"cmd": "shutoff", "room_id": 1}
{"cmd": "calibrate", "room_id": 2, "ppl": 450}
{"cmd": "reset_counters"}
```

---

## Wiring Summary

### 3 Room ESP32s — each gets 1 YF-S201 sensor
Each sensor: Red → 5V, Black → GND, Yellow → GPIO 26

### Main ESP32 — WiFi + Firebase + Centralized Valves

- Calibrated YF-S201 flow sensor: Red → 5V, Black → GND, Yellow → GPIO 34
- 2CH relay: IN1 → GPIO 19 (Solenoid 1), IN2 → GPIO 18 (Solenoid 2)
- No SSR on main — room power SSRs live on the room ESP32s; each room also drives its own solenoid via its 1-ch relay (GPIO 25)
- WiFi connects to Firebase RTDB via mobizt Firebase-ESP-Client

> **ESP-NOW:** No wiring between room ESP32s and main ESP32 — communication is wireless via ESP-NOW protocol.

---

## Wiring Resources

| Resource | Description | Link |
|---|---|---|
| **Interactive Wiring Diagram** | Cirkit Designer (clickable, zoomable) | [app.cirkitdesigner.com/project/b0b4579e-313d-4faa-9cd1-f955daa204a5](https://app.cirkitdesigner.com/project/b0b4579e-313d-4faa-9cd1-f955daa204a5) |
| **Static Wiring Diagram** | PNG image for docs | `../wiring/smartrooms.png` |

---

## 3D Enclosure Models

All 3D models and Fusion 360 source files are in the `models/` folder:

| File | Description |
|---|---|
| `TapFlow.f3d` | Fusion 360 source file (editable) |
| `tapflow_view_1.png` | Fixture view 1 |
| `tapflow_view_2.png` | Fixture view 2 |
| `tapflow_view_3.png` | Fixture view 3 |
| `tapflow_view_4.png` | Fixture view 4 |
| `tapflow_view_5.png` | Fixture view 5 |
| `tapflow_view_6.png` | Fixture view 6 |
| `tapflow_view_7.png` | Fixture view 7 |
| `tapflow_view_8.png` | Fixture view 8 |

> Use the `.f3d` file in Fusion 360 to modify the enclosure design, add mounting holes, or adjust dimensions for different components.

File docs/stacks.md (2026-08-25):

# Technology Stack — Water Meter with Leak Detection

> **Architecture:** Room ESP32s → ESP-NOW → Main ESP32 → WiFi → Firebase RTDB → Next.js on Vercel

---

## ESP32 Firmware Stack

| Layer | Technology | Version | Purpose |
|---|---|---|---|
| **Framework** | Arduino framework (esp32 core) | ≥ 2.0.x | Mature, well-documented, large ecosystem |
| **IDE** | Arduino IDE 2.x | Latest | ESP32 board support, Library Manager, Serial Monitor |
| **Language** | C++11/Arduino | — | Standard for ESP32 |
| **JSON** | [ArduinoJson](https://arduinojson.org/) | ≥ 7.x | Payload serialization |
| **ESP-NOW** | esp_now.h (built-in) | Built-in | Wireless room-to-main communication |
| **RFID** | [MFRC522](https://github.com/miguelbalboa/rfid) | ≥ 1.4.x | SPI RFID reader for usage tracking |
| **Firebase** | [Firebase-ESP-Client (mobizt)](https://github.com/mobizt/Firebase-ESP-Client) | ≥ 4.x | RTDB read/write/stream/callbacks via WiFi |
| **WiFi** | WiFi.h (Arduino) | Built-in | Station mode (for ESP-NOW + OTA) |
| **NTP** | NTPClient / configTime() | Built-in | Time sync for timestamped data |
| **OTA** | ArduinoOTA | Built-in | Over-the-air firmware updates |
| **SPIFFS** | SPIFFS (via LittleFS) | Built-in | Offline data logging |

### ArduinoJson Usage (v7+)

```cpp
#include <ArduinoJson.h>

JsonDocument doc;  // v7+ uses JsonDocument (replaces StaticJsonDocument)

doc["room_id"] = 1;
doc["ts"] = millis();
doc["pulses"] = 127;
doc["flow_rate_lpm"] = 2.34;
doc["volume_ml"] = 456;
doc["leak_alert"] = false;

serializeJson(doc, Serial);
Serial.println();  // Newline delimiter for JSON Lines
```

---

## ESP-NOW Communication Stack

| Layer | Technology | Protocol | Details |
|---|---|---|---|
| **Wireless** | ESP-NOW (Espressif) | 2.4 GHz | Low-latency, no WiFi router needed |
| **Range** | ~200m outdoor, ~30m indoor | — | Sufficient for room-to-main distance |
| **Payload** | Binary struct | — | Room ID, pulses, flow rate, volume, leak flag |
| **Frequency** | Every 5 sec | — | Matches USB serial interval |

---

## WiFi + Firebase Stack (Main ESP32)

| Layer | Technology | Version | Purpose |
|---|---|---|---|
| **WiFi** | WiFi.h (Arduino) | Built-in | Connect to local WiFi network |
| **Firebase SDK** | [Firebase-ESP-Client (mobizt)](https://github.com/mobizt/Firebase-ESP-Client) | ≥ 4.x | RTDB read/write/stream/callbacks |
| **Stream** | Firebase.onValue() | — | Real-time listener for commands from dashboard |
| **Callback** | Firebase.setCallback() | — | React to data changes on Firebase |
| **Auth** | Firebase ESP32 Auth | — | Optional: authenticate ESP32 with Firebase |

---

## Web Dashboard Stack (Next.js + Firebase)

| Layer | Technology | Purpose |
|---|---|---|
| **Framework** | [Next.js](https://nextjs.org/) ≥ 14.x | React framework with App Router |
| **Language** | TypeScript | Type safety |
| **Styling** | Tailwind CSS | Utility-first CSS |
| **Charts** | Chart.js / Recharts | Real-time flow rate charts |
| **Auth** | [Firebase Authentication](https://firebase.google.com/docs/auth) | Email/password, Google sign-in |
| **Database** | [Firebase Realtime Database](https://firebase.google.com/docs/database) | Real-time data sync |
| **Firebase SDK** | firebase (JS SDK) | Client-side Firebase integration |
| **Hosting** | [Vercel](https://vercel.com/) | Auto-deploy from Git, serverless |
| **Real-time** | Firebase RTDB `onValue()` listener | Instant data updates in browser |

---

## Communication Summary

| Path | Protocol | Data Format | Frequency |
|---|---|---|---|
| Sensor → Room ESP32 | Pulse (GPIO interrupt) | Rising edge | Continuous |
| Room ESP32 → Main ESP32 | ESP-NOW (wireless) | Binary payload | Every 5 sec |
| Main ESP32 → Firebase | WiFi + HTTPS | JSON (RTDB) | Every 5 sec |
| Firebase → Main ESP32 | WiFi + HTTPS | Callbacks/Streams | On command |
| Firebase → Next.js | WebSocket (RTDB) | Real-time sync | Instant |
| Main ESP32 → Relay → Solenoid | GPIO HIGH/LOW | Digital signal | Smart: ON when flow, OFF when idle |
| User → Dashboard | HTTPS | Internet | Firebase Auth login |

---

## Development Tools

| Tool | Purpose |
|---|---|
| **Arduino IDE** | Build, upload, and debug ESP32 firmware (C++) |
| **Firebase Console** | Manage RTDB, Authentication, project settings |
| **Vercel Dashboard** | Deploy Next.js app, manage domains |
| **Serial Monitor** | ESP32 debug output (921600 baud) |
| **Git + GitHub** | Version control + Vercel auto-deploy |

---

## Stack Decision Matrix

| Requirement | Chosen | Alternatives Considered | Why This Won |
|---|---|---|---|
| **Web Framework** | **Next.js** | Flask, Django, Express | React ecosystem, Vercel auto-deploy, TypeScript |
| **Database** | **Firebase Realtime Database** | SQLite, PostgreSQL, Supabase | Real-time sync, no backend server, free tier |
| **Authentication** | **Firebase Authentication** | Custom JWT, Auth0, Clerk | Free, integrates with RTDB, Google sign-in |
| **Hosting** | **Vercel** | Netlify, AWS | Free tier, auto-deploy from Git, serverless |
| ESP32 38-pin ESP32 Dev Module | 30-pin, ESP32-C3, ESP8266 | More GPIOs, ESP-NOW support, 4 boards total |
| **mobizt Firebase-ESP-Client** | Direct ESP32 → Firebase, stream + callbacks | Custom backend | No extra hardware needed |

---

## Stack Summary

- **Room ESP32s ×3**: Arduino + ArduinoJson + MFRC522 RFID → 1 flow sensor (leak detection) each → ESP-NOW to main
- **Main ESP32 (centralized)**: ESP-NOW receiver + 2× relay (solenoid valves) + calibrated flow sensor
- **Main ESP32**: WiFi + mobizt Firebase-ESP-Client → pushes to Firebase RTDB directly
- **Firebase**: Realtime Database (data) + Authentication (user login)
- **Next.js on Vercel**: Web dashboard with real-time Firebase sync, deployed from Git
- ESP32 handles everything — sensors, RFID, relays, WiFi, Firebase

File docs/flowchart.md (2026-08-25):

# Flowchart — Water Meter with Leak Detection (ESP-NOW + WiFi → Firebase)

## 1. Main System Flow (High-Level)

> Mermaid-based diagram (SVG export removed; source below)

<details>
<summary><b> Mermaid Source</b> (click to expand)</summary>

```mermaid
flowchart TD
    Start((Room ESP32 Start)) --> Init[Initialize Flow Sensor + ESP-NOW]
    Init --> MainLoop[Enter Main Loop]
    
    MainLoop --> ReadPulses[Read Pulse Counter via ISR]
    ReadPulses --> CalcFlow[Calculate Flow Rate + Volume]
    CalcFlow --> LocalRules[Apply Local Leak Rules]
    
    LocalRules --> Interval{Send Interval 5s?}
    Interval -->|Yes| SendESPNOW[Send Data via ESP-NOW to Main]
    Interval -->|No| MainLoop
    
    SendESPNOW --> MainLoop
```

> Room ESP32s transmit wirelessly via ESP-NOW. The main ESP32 aggregates and pushes to Firebase via WiFi.

</details>

---

## 2. Main ESP32 → Firebase Data Flow

> Mermaid-based diagram (SVG export removed; source below)

<details>
<summary><b> Mermaid Source</b> (click to expand)</summary>

```mermaid
flowchart LR
    subgraph Rooms["Room ESP32s x3"]
        RFID1[RFID] --> ESP1[Room 1]
        R1[Flow Sensor] --> ESP1
        ESP1 --> SSR1[SSR + Solenoid]
        ESP1 --> TX1[ESP-NOW TX]

        RFID2[RFID] --> ESP2[Room 2]
        R2[Flow Sensor] --> ESP2
        ESP2 --> SSR2[SSR + Solenoid]
        ESP2 --> TX2[ESP-NOW TX]

        RFID3[RFID] --> ESP3[Room 3]
        R3[Flow Sensor] --> ESP3
        ESP3 --> SSR3[SSR + Solenoid]
        ESP3 --> TX3[ESP-NOW TX]
    end

    subgraph Main["Main ESP32"]
        TX1 -.->|wireless| RX[ESP-NOW RX]
        TX2 -.->|wireless| RX
        TX3 -.->|wireless| RX
        RX --> AGG[Aggregate Room Data]
        AGG --> WIFI[WiFi + mobizt SDK]
    end

    subgraph Firebase["Firebase Cloud"]
        WIFI -.->|WiFi + mobizt| RTDB[(Realtime Database)]
        AUTH[Firebase Auth] --> NEXTJS
    end

    subgraph Vercel["Vercel Hosting"]
        RTDB --> NEXTJS[Next.js Dashboard]
    end
```

</details>

---

## 3. RFID Tap + Smart Solenoid Control

> Mermaid-based diagram (SVG export removed; source below)

<details>
<summary><b> Mermaid Source</b> (click to expand)</summary>

```mermaid
flowchart TD
    Start((Customer Enters Room)) --> Tap[Tap RFID Card on MFRC522]
    Tap --> Read[Read Card UID]
    Read --> Valid{Valid Card for This Room?}
    
    Valid -->|No| Deny[LED Red Blink - Access Denied]
    Deny --> Start
    
    Valid -->|Yes| SSR_ON[SSR ON - Room Powered]
    SSR_ON --> SOL_ON[Solenoid ON - Water Flows]
    SOL_ON --> LED_G[LED Green - Session Active]
    
    LED_G --> FlowCheck{Flow Sensor Active?}
    
    FlowCheck -->|Flow Detected| SOL_STAY[Solenoid Stays ON]
    SOL_STAY --> FlowCheck
    
    FlowCheck -->|No Flow for N sec| SOL_OFF[Solenoid OFF - Prevent Overheating]
    SOL_OFF --> WaitFlow{Flow Detected?}
    
    WaitFlow -->|Yes| SOL_ON2[Solenoid ON Again]
    SOL_ON2 --> FlowCheck
    
    WaitFlow -->|Timeout X min| SSR_OFF[SSR OFF - Session Ends]
    SSR_OFF --> End((Room Powers Off))
    
    FlowCheck -->|Leak Detected| EMERGENCY[Emergency: SSR OFF + Solenoid OFF]
    EMERGENCY --> Alert[Send Alert via ESP-NOW]
    Alert --> End
```

</details>

> **Smart Solenoid Logic:** The solenoid is ONLY energized when the flow sensor detects water usage. When no flow is detected for N seconds, the solenoid automatically turns OFF to prevent overheating. It turns back ON when flow resumes. This allows continuous water use without damaging the solenoid.

---

## 4. Leak Detection Rules (6 Scenarios)

> Mermaid-based diagram (SVG export removed; source below)

<details>
<summary><b> Mermaid Source</b> (click to expand)</summary>

```mermaid
flowchart TD
    Check{Flow Detected?}
    Check -->|No Flow| OK[Normal - No Leak]
    Check -->|Flow > 0.01 L/min| Rule1{RFID Session Active?}
    
    Rule1 -->|No Session| LEAK1[LEAK: No Customer + Flow = Pipe Burst / Broken Fitting]
    Rule1 -->|Session Active| Rule2{Solenoid ON?}
    
    Rule2 -->|Solenoid OFF| LEAK2[LEAK: Solenoid Stuck Open = Hardware Failure]
    Rule2 -->|Solenoid ON| Rule3{Flow Duration?}
    
    Rule3 -->|Less than 30 min| Rule4{Flow Rate?}
    Rule3 -->|More than 30 min| LEAK3[LEAK: Continuous Flow = Stuck Valve / Running Toilet]
    
    Rule4 -->|0.1 - 0.5 L/min for 5+ min| LEAK4[LEAK: Drip = Loose Fitting / Dripping Faucet]
    Rule4 -->|Normal usage| Rule5{Night Time 22:00-05:00?}
    
    Rule5 -->|Yes + No Session| LEAK5[LEAK: Night Flow = Suspicious / Unauthorized Use]
    Rule5 -->|No| OK2[Normal Usage - Session Active]
    
    LEAK1 --> EMERGENCY[Emergency Shutoff: SSR OFF + Solenoid OFF]
    LEAK2 --> EMERGENCY
    LEAK3 --> EMERGENCY
    LEAK4 --> EMERGENCY
    LEAK5 --> EMERGENCY
    EMERGENCY --> ALERT[Send Alert via ESP-NOW to Main ESP32]
```

</details>

> **6 Leak Detection Scenarios:**
> 1. **No RFID + Flow** = No customer in room but water flowing → CRITICAL
> 2. **Solenoid OFF + Flow** = Valve closed but flow persists → Hardware failure
> 3. **Continuous flow > 30 min** = Stuck valve / running toilet
> 4. **Drip (0.1–0.5 L/min) > 5 min** = Slow leak from loose fitting
> 5. **Night flow (22:00–05:00) no session** = Suspicious unauthorized usage
> 6. **Session ended + Flow** = Customer left but water continues → Solenoid stuck open
>
> **All rules trigger emergency shutoff:** SSR OFF + Solenoid OFF + Alert sent to Firebase → Next.js dashboard.

---

## 5. ESP32 ISR Pulse Processing

> Mermaid-based diagram (SVG export removed; source below)

<details>
<summary><b> Mermaid Source</b> (click to expand)</summary>

```mermaid
flowchart TD
    Pulse[/Pulse from Flow Sensor/] --> ISR[ISR Triggered]
    ISR --> Time[Read Millis]
    Time --> Debounce{Debounce Check dt greater than 5ms?}
    Debounce -->|Yes| Count[Increment Pulse Counter]
    Debounce -->|No| Ignore[Ignore - Bounce]
    Count --> Update[Update Last Pulse Time]
    Ignore --> Return[Return to Main Loop]
    Update --> Return
```

</details>

---

## 4. Firebase RTDB Data Structure

> Mermaid-based diagram (SVG export removed; source below)

<details>
<summary><b> Mermaid Source</b> (click to expand)</summary>

```mermaid
flowchart TD
    Raw[/Raw Serial JSON/] --> Parse[Parse JSON]
    Parse --> Loop{For Each Fixture}
    Loop -->|Fixture 1-3| Extract[Extract Raw Metrics]
    Extract --> Compute[Compute Derived Metrics]
    
    Compute --> F1[flow_rate L/min]
    Compute --> F2[volume_ml]
    Compute --> F3[inlet_balance]
    Compute --> F4[continuous_flow_duration]
    
    F1 --> Rules[Local Leak Rules]
    F2 --> Rules
    F3 --> Rules
    F4 --> Rules
    
    Rules --> Decision{Leak Detected?}
```

</details>

---

## 5. Local Leak Detection Rules

> Mermaid-based diagram (SVG export removed; source below)

<details>
<summary><b> Mermaid Source</b> (click to expand)</summary>

```mermaid
flowchart TD
    Features[/Sensor Readings/] --> Rule1{Inlet Balance OK?}
    Rule1 -->|Yes| Rule2{Continuous Flow > 30 min?}
    Rule1 -->|No| Alert1[Hidden Leak Alert]
    
    Rule2 -->|Yes| Alert2[Stuck Valve Alert]
    Rule2 -->|No| Rule3{Drip 0.1-0.5 L/min > 5 min?}
    
    Rule3 -->|Yes| Alert3[Drip Leak Alert]
    Rule3 -->|No| OK[Normal - No Leak]
    
    Alert1 --> Notify[In-App Notification]
    Alert2 --> Notify
    Alert3 --> Notify
    
    Notify --> Cmd[Send Command via Serial]
```

</details>

---

## 6. ESP32 Serial Command Execution

> Mermaid-based diagram (SVG export removed; source below)

<details>
<summary><b> Mermaid Source</b> (click to expand)</summary>

```mermaid
flowchart TD
    Serial[/Serial Read JSON/] --> CmdType{Command Type?}
    
    CmdType -->|calibrate| CalStart[Start Calibration Routine]
    CmdType -->|reboot| Reboot[Reboot ESP32]
    CmdType -->|reset_counters| Reset[Reset Pulse Counters]
    CmdType -->|set_ppl| SetPPL[Update PPL Values]
    CmdType -->|sleep| Sleep[Deep Sleep Duration]
    
    CalStart --> CalStatus[Update Status and LED]
    Reboot --> CalStatus
    Reset --> CalStatus
    SetPPL --> CalStatus
    Sleep --> CalStatus
    
    CalStatus --> Ack[Send Acknowledgment JSON]
```

</details>

---

## 7. Local Leak Detection Rules (ESP32 Fallback)

> Mermaid-based diagram (SVG export removed; source below)

<details>
<summary><b> Mermaid Source</b> (click to expand)</summary>

```mermaid
flowchart TD
    Cycle[Every Read Cycle] --> Rule1[Rule 1: Hidden Leak]
    Rule1 --> Check1{Inlet Volume GT Sum Fixtures plus 10%?}
    Check1 -->|Yes| Alert1[Hidden Leak Alert]
    Check1 -->|No| OK1[Balance OK]
    
    Cycle --> Rule2[Rule 2: Continuous Flow]
    Rule2 --> Loop{For Each Fixture}
    Loop --> Check2{Pulse GT 0 for GT 30 min?}
    Check2 -->|Yes| Alert2[Stuck Valve or Running Toilet]
    Check2 -->|No| OK2[Fixture OK]
    
    Cycle --> Rule3[Rule 3: Drip Detection]
    Loop2{For Each Fixture} --> Check3{Flow 0.1-0.5 L/min for GT 5 min?}
    Check3 -->|Yes| Alert3[Drip Leak Suspected]
    Check3 -->|No| OK3[No Drip]
    
    Alert1 --> SerialAlert[Send Alert via Serial]
    Alert2 --> SerialAlert
    Alert3 --> SerialAlert
```

</details>

---

## 8. Full System Data Flow

> Mermaid-based diagram (SVG export removed; source below)

<details>
<summary><b> Mermaid Source</b> (click to expand)</summary>

```mermaid
flowchart LR
    %% Physical Layer
    Water[/Water Flow/]:::physical --> Sensor[YF-S201 Flow Sensor]:::physical
    Sensor --> Pulse[/Pulse Signal/]:::physical
    
    %% Firmware Layer
    Pulse --> ISR[ISR Pulse Counter]:::firmware
    ISR --> Debounce[Debounce 5ms]:::firmware
    Debounce --> Calc[Calculate Flow and Volume]:::firmware
    Calc --> LocalRules[Local Leak Rules]:::firmware
    Calc --> SerialOut[USB Serial Output]:::firmware
    LocalRules --> SerialOut
    
    %% USB Layer
    SerialOut -->|USB CDC/ACM 921600 baud| USB[USB Cable]:::usb
    
    %% Firebase Layer
    SerialOut -->|WiFi + mobizt| Firebase[Firebase RTDB]:::backend
    Firebase --> Parser[JSON Parser]:::backend
    Parser --> LocalRules[Local Leak Rules]:::backend
    LocalRules --> AlertEngine[Alert Engine]:::backend
    AlertEngine --> Notify[In-App Notification]:::user
    AlertEngine --> FB[(Firebase RTDB)]:::backend
    
    %% User Layer
    FB --> Dashboard[Next.js Dashboard on Vercel]:::user
    USB -->|Commands| CmdHandler[Command Handler]:::firmware
    
    classDef physical fill:#e1f5fe,stroke:#0288d1,stroke-width:2px
    classDef firmware fill:#fff3e0,stroke:#f57c00,stroke-width:2px
    classDef usb fill:#e8f5e9,stroke:#388e3c,stroke-width:2px
    classDef backend fill:#f3e5f5,stroke:#7b1fa2,stroke-width:2px
    classDef user fill:#fffde7,stroke:#f9a825,stroke-width:2px
```

</details>

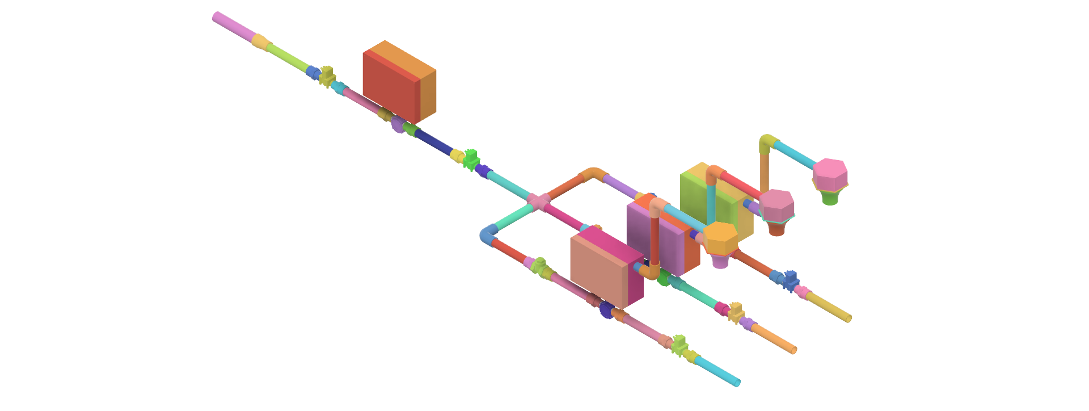
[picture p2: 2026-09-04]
models/tapflow_view_6.png

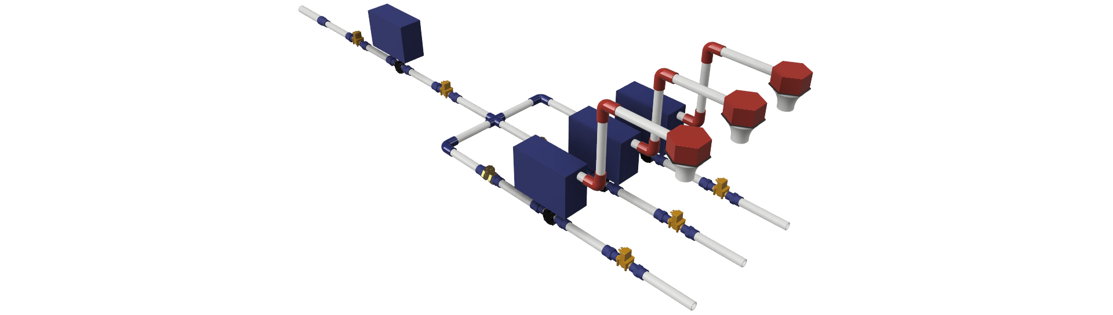
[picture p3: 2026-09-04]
models/tapflow_view_2.png

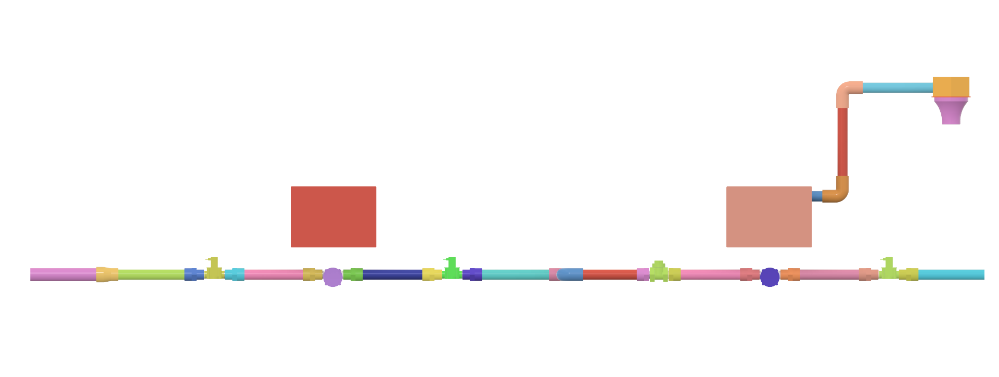
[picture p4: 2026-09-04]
models/tapflow_view_7.png

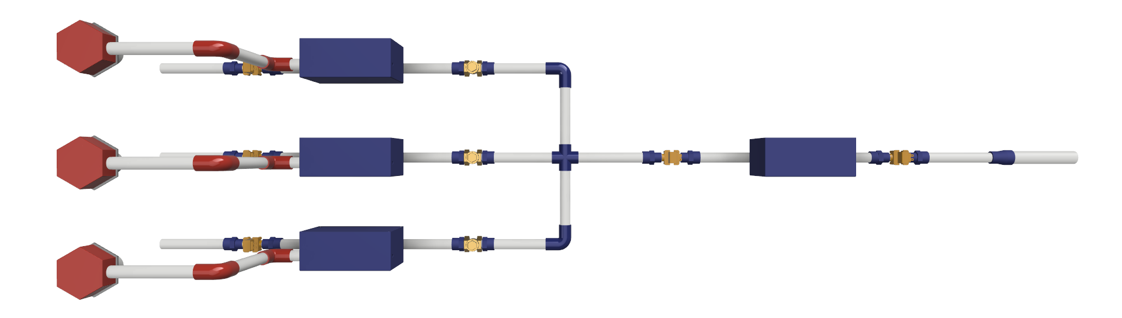
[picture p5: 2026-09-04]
models/tapflow_view_4.png

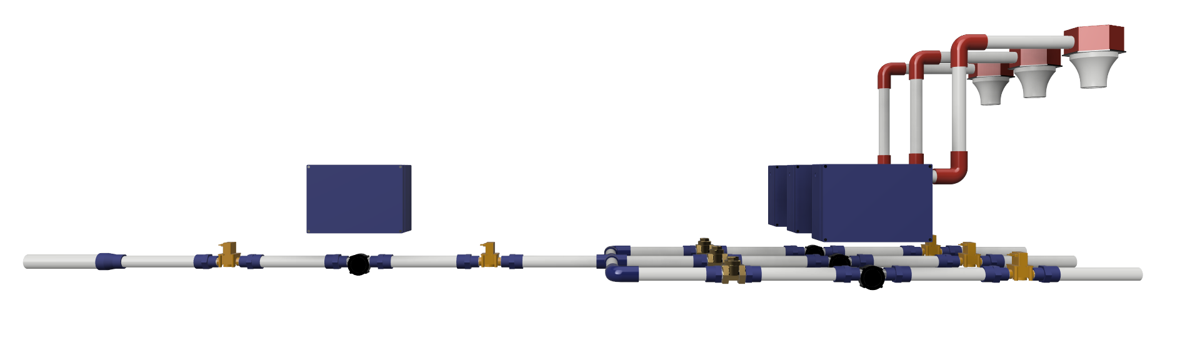
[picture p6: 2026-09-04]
models/tapflow_view_3.png

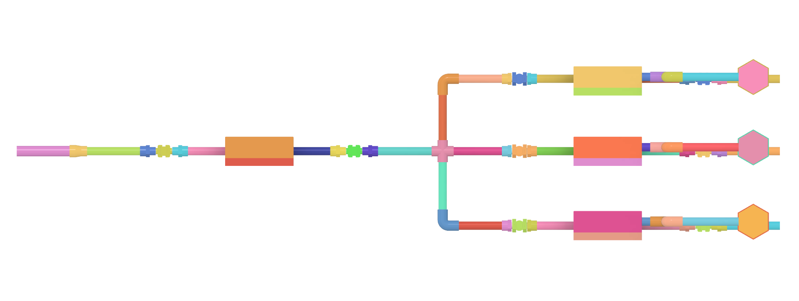
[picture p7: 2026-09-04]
models/tapflow_view_8.png

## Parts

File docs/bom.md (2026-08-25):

# Bill of Materials (BOM) — TapFlow

> **System:** Main ESP32 (WiFi + 2CH relay + 2 central solenoids + calibrated flow sensor) ← ESP-NOW ← 3 Room ESP32s (RFID + leak detection flow sensor + SSR + room solenoid) → Firebase RTDB → Next.js on Vercel
> **Supplier Priority:** [Makerlab Electronics](https://shopee.ph/makerlabelectronics) → 4–5 alternatives  
> **Prices:** Estimated in Philippine Peso (₱), July 2026

---

## Waterline Structure

```
Water Tank (500-1000L)
    │
    ▼
Fittings → 1" Pipe
    │
    ▼
Reducer Fittings (1" → 1/2")
    │
    ▼
Solenoid Valve 1 (12V NC) ── Main ESP32 (2CH Relay IN1)
    │
    ▼
Flow Sensor (calibrated) ── Main ESP32 (GPIO 34)
    │
    ▼
Solenoid Valve 2 (12V NC) ── Main ESP32 (2CH Relay IN2)
    │
    ▼
T-Connector → 1/2" PPE Pipe → Each Room
    ├──→ Room 1 (Bathroom)
    ├──→ Room 2 (Kitchen)
    └──→ Room 3 (Shower)
```

> **Design:** Dual solenoid valves in series for redundancy — if one fails, the other can still shut off water. Flow sensor placed between solenoids for accurate metering. T-connectors distribute water to each room using 1/2" PPE pipe.

---

## 1. Core Components

| # | Item | Qty | Unit (₱) | Total (₱) | Link |
|---|---|-----|---|---|---|
| 1 | **ESP32 38-Pin Dev Board** (ESP32 Dev Module, CP2102, WiFi + BLE) | **4** | ₱450 | **₱1,800** | [Makerlab Shopee](https://shopee.ph/makerlabelectronics/search?keyword=esp32%2038pin) |
| 2 | **ESP32 38-Pin Expansion Board** (screw terminals, labeled) | **4** | ₱180 | **₱720** | [Makerlab Shopee](https://shopee.ph/makerlabelectronics/search?keyword=esp32%20expansion%20board) |
| 3 | **MFRC522 RFID Reader Module** (SPI, 13.56MHz) | **3** | ₱80 | **₱240** | [Makerlab Shopee](https://shopee.ph/makerlabelectronics/search?keyword=mfrc522) |
| 4 | **RFID Card / Tag** (Mifare Classic 1K) | 3+ | ₱30 | ₱90 | [Makerlab Shopee](https://shopee.ph/makerlabelectronics/search?keyword=mifare%20classic%201k) |
| 5 | **YF-S201 Water Flow Sensor** 1/2" thread, Hall-effect | **4** | ₱180 | **₱720** | [Makerlab Shopee](https://shopee.ph/makerlabelectronics/search?keyword=yf-s201%20flow%20sensor) |
| 6 | **2CH Relay with Optocoupler** (main ESP32 — controls 2 central solenoid valves) | **1** | ₱90 | **₱90** | [Makerlab Shopee](https://shopee.ph/makerlabelectronics/search?keyword=2%20channel%20relay%20optocoupler) |
| 7 | **1-ch Relay 10A** (optocoupler, per-room solenoid valve) | **3** | ₱50 | **₱150** | [Makerlab Shopee](https://shopee.ph/makerlabelectronics/search?keyword=relay%2010a%20optocoupler) |
| 8 | **Fotek 40A SSR** (per-room power — lights/fan/appliances) | **3** | ₱280 | **₱840** | [Makerlab Shopee](https://shopee.ph/makerlabelectronics/search?keyword=fotek%20ssr%2040a) |
| 9 | **Solenoid Valve 1/2" NC** (12V DC, normally closed) — 2 central (main) + 3 room | **5** | ₱250 | **₱1,250** | [Makerlab Shopee](https://shopee.ph/makerlabelectronics/search?keyword=solenoid%20valve%2012v) |
| 10 | **Check Valve 1/2"** Brass (non-return) | 3 | ₱120 | ₱360 | [Shopee Hardware](https://shopee.ph/search?keyword=check%20valve%201%2F2%20brass) |
| 11 | **1/2" PPE Pipe** (Polypropylene, 4m length) | 2 | ₱150 | ₱300 | [Shopee Hardware](https://shopee.ph/search?keyword=ppe%20pipe%201%2F2) |
| 12 | **1/2" PPE Pipe Fittings** (tees, elbows, couplers, nipples) | 1 set | ₱200 | ₱200 | [Shopee Hardware](https://shopee.ph/search?keyword=ppe%20pipe%20fitting%20set) |
| 13 | **PTFE Thread Seal Tape** (Teflon, 10m roll) | 2 | ₱20 | ₱40 | [Shopee Hardware](https://shopee.ph/search?keyword=teflon%20tape) |
| 14 | **PPR Welding Machine** (for heat-fusing PPE joints) | 1 | ₱350 | ₱350 | [Shopee Hardware](https://shopee.ph/search?keyword=ppr%20welding%20machine) |

**Core Subtotal:** **₱7,150**

---

## 2. Power Supply

| # | Item | Qty | Unit (₱) | Total (₱) | Link |
|---|---|-----|---|---|---|
| 15 | **220V AC to 12V 5A Switching Power Supply** (S-60-12, 60W, LRS-50/60-12) | **4** | ₱280 | **₱1,120** | [Makerlab Shopee](https://shopee.ph/makerlabelectronics/search?keyword=12v%205a%20power%20supply) |
| 16 | **12V to 5V Buck Converter** (LM2596S, DC-DC Step-Down Module, USB output) | **4** | ₱65 | **₱260** | [Makerlab Shopee](https://shopee.ph/makerlabelectronics/search?keyword=lm2596s%20buck%20converter) |
| 17 | **USB to Micro USB Data Cable** (braided, 1m) | **4** | ₱120 | **₱480** | [Makerlab Shopee](https://shopee.ph/makerlabelectronics/search?keyword=micro%20usb%20cable) |
| 18 | **12V Male DC Power Jack Adapter** (5.5×2.1mm, screw terminal) | **4** | ₱9 | **₱36** | [Makerlab Shopee](https://shopee.ph/makerlabelectronics/search?keyword=dc%20power%20jack%20adapter) |

**Power Subtotal:** **₱1,896**

> **Note:** Each ESP32 (3 room + 1 main) has its own dedicated 12V 5A power supply, buck converter, and DC jack adapter. The DC jack adapter converts the PSU's screw terminal output to a 5.5×2.1mm barrel plug for the expansion board's power jack. The main ESP32 PSU powers 12V solenoid valves directly via 2CH relay.

---

## 3. Enclosure & Mounting

| # | Item | Qty | Unit (₱) | Total (₱) | Link |
|---|---|-----|---|---|---|
| 19 | **Waterproof ABS Enclosure Box IP67** 175×125×75mm | **4** | ₱280 | **₱1,120** | [Makerlab Shopee](https://shopee.ph/makerlabelectronics/search?keyword=waterproof%20enclosure%20ip67) |
| 20 | **Cable Glands** PG9 / PG11 (waterproof entry) | 6 | ₱15 | ₱90 | [Makerlab Shopee](https://shopee.ph/makerlabelectronics/search?keyword=cable%20gland%20pg9) |
| 21 | **Heat Shrink Tube Set** (assorted sizes) | 1 | ₱60 | ₱60 | [Makerlab Shopee](https://shopee.ph/makerlabelectronics/search?keyword=heat%20shrink%20tube) |
| 22 | **Cable Ties** 100mm (100pc) | 1 | ₱30 | ₱30 | [Makerlab Shopee](https://shopee.ph/makerlabelectronics/search?keyword=cable%20tie) |
| 23 | **M3 Screws + Standoffs Kit** (PCB mounting) | 1 | ₱60 | ₱60 | [Makerlab Shopee](https://shopee.ph/makerlabelectronics/search?keyword=m3%20standoff) |
| 24 | **Double-sided Tape / Velcro** (mounting sensors) | 1 | ₱30 | ₱30 | [Shopee Hardware](https://shopee.ph/search?keyword=double%20sided%20tape%20heavy%20duty) |

**Enclosure Subtotal:** **₱550**

> **Note:** IP67 waterproof enclosure provides excellent protection for outdoor/wet environments. 175×125×75mm size fits ESP32, expansion board, buck converter, and room for cable management.

---

## Total Cost Summary

| Tier | Category | ₱ | Notes |
|---|---|---|---|
| **MVP** | 1 room (RFID + leak sensor + SSR + solenoid) + main (2CH relay, 2 solenoids, calibrated sensor) + PPE pipe | **~₱9,596** | Prove ESP-NOW + Firebase concept |
| **Standard** | 3 rooms + main + enclosure + PPE pipe + welding machine | **~₱9,596** | Full multi-room system |
| **Complete** | Standard + Firebase (free tier) + Vercel (free tier) | **~₱9,596** | Production-ready! |

---

## Recommended Seller: Makerlab Electronics

| Platform | Store | Rating | Notes |
|---|---|---|---|
| **Shopee** | [Makerlab Electronics](https://shopee.ph/makerlabelectronics) | 4.9 | Fast shipping, good stock |
| **Lazada** | [Makerlab Electronics](https://www.lazada.com.ph/shop/makerlab-electronics/) | 4.8 | Wider payment options |

### Alternative Sellers (4–5)

| Store | Platform | Rating | Specializes In |
|---|---|---|---|
| [e-Gizmo](https://shopee.ph/e-gizmo) | Shopee | 4.8 | Arduino/ESP32 parts, sensors |
| [Cytron Technologies](https://shopee.ph/cytrontechnologies) | Shopee | 4.9 | Robotics, IoT, sensors |
| [DIY Electronics](https://shopee.ph/diy_electronics) | Shopee | 4.7 | General electronics |
| [Handson Technology](https://www.lazada.com.ph/shop/handsome-technology/) | Lazada | 4.8 | Sensors, power supplies |

---

## Wiring Summary

### Room ESP32 (×3) — each gets RFID + flow sensor + SSR + relay + solenoid

**MFRC522 RFID (SPI):**
| RFID Pin | ESP32 Pin |
|---|---|
| SDA (NSS) | GPIO 5 |
| SCK | GPIO 18 |
| MOSI | GPIO 23 |
| MISO | GPIO 19 |
| RST | GPIO 21 |
| 3.3V | 3V (expansion board) |
| GND | GND |

**YF-S201 Flow Sensor (leak detection — uncalibrated):**
| Wire | Pin |
|---|-----|
| Red (VCC) | 5V |
| Black (GND) | GND |
| Yellow (Signal) | GPIO 26 |

**Fotek 40A SSR (room power — lights, fan, appliances):**
| Wire | Pin |
|---|-----|
| Input + | GPIO 27 |
| Input - | GND |
| Output 1 | 220V line |
| Output 2 | Appliance1st wire |
| Appliance 2nd wire | 220V line |

**1-ch Relay 10A (solenoid valve control):**
| Wire | Pin |
|---|-----|
| VCC | 5V |
| GND | GND |
| IN | GPIO 25 |
| COM | Solenoid + |
| NO | PSU + (12V) |
| Solenoid - | PSU - (directly) |

**Power:** Expansion board jack input → 12V switching PSU (accepts 6.5–16V)

### Main ESP32 — WiFi + Firebase + Centralized Control

**YF-S201 Flow Sensor (calibrated — for accurate metering):**
| Wire | Pin |
|---|-----|
| Red (VCC) | 5V (expansion board) |
| Black (GND) | GND |
| Yellow (Signal) | GPIO 34 |

**2CH Relay with Optocoupler (solenoid valve control):**
| Wire | Pin |
|---|-----|
| VCC | 5V (expansion board) |
| GND | GND |
| IN1 | GPIO 19 |
| IN2 | GPIO 18 |
| COM1 | Solenoid 1 + |
| COM2 | Solenoid 2 + |
| NO1 | PSU + (12V) |
| NO2 | PSU + (12V) |
| Solenoid 1 - | PSU - (directly) |
| Solenoid 2 - | PSU - (directly) |

**Reset Button (Arcade — WiFi credentials reset):**
| Wire | Pin |
|---|-----|
| Pin 1 | GND (expansion board) |
| Pin 2 | GPIO 27 |

**Power:** Expansion board jack input → 12V switching PSU (accepts 6.5–16V)

| Connection | Notes |
|---|---|
| WiFi | Connects to local network, pushes to Firebase RTDB |
| ESP-NOW | Receives RFID + leak alerts from room ESP32s |
| Power | 12V from PSU (ESP32 + sensors + solenoids) |

> **Architecture:** Main ESP32 is centralized before the rooms. It controls both solenoid valves via 2CH relay and reads the calibrated flow sensor. Room ESP32s handle RFID, flow sensor (leak detection), SSR (room power), and relay (solenoid) — they wirelessly report to main via ESP-NOW.
> **Note:** Solenoid valves are 12V NC (normally closed). Relay fires to OPEN valve (allow water flow). On leak detection, relay turns OFF → solenoid closes → water stops.

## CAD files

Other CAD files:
models/TapFlow.f3d

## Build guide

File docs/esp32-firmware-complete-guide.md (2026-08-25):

# ESP32 Firmware Complete Guide — ESP-NOW + Firebase (mobizt)

> **Target:** 3 Room ESP32s + 1 Main ESP32 (38-pin Dev Module with Expansion Board)  
> **Sensors:** 3× YF-S201 Flow Sensors (1 per room), 3× MFRC522 RFID  
> **Communication:** ESP-NOW (room→main) + WiFi → Firebase RTDB (mobizt Firebase-ESP-Client)  
> **Relays:** Fotek 40A SSR per room (room power) + 1-ch relay per room (room solenoid) + 2CH relay on main (2 central solenoid valves)  
> **IDE:** Arduino IDE 2.x (Windows/macOS/Linux)  
> **Libraries:** ArduinoJson (≥ 7.x), MFRC522, Firebase-ESP-Client by mobizt (≥ 4.x), ESP-NOW (built-in)  
> **Audience:** Complete setup from hardware to deployed firmware

---

## Table of Contents

1. [Hardware Overview](#hardware-overview)
2. [Arduino IDE Installation](#arduino-ide-installation)
3. [ESP32 Board Support Configuration](#esp32-board-support-configuration)
4. [ArduinoJson Library Setup](#arduinojson-library-setup)
5. [Firmware Architecture & File Structure](#firmware-architecture--file-structure)
6. [Main Loop & Sensor Management](#main-loop--sensor-management)
7. [USB Serial Communication](#usb-serial-communication)
8. [Local Leak Detection Rules (Offline Fallback)](#local-leak-detection-rules-offline-fallback)
9. [Configuration (`config.h`)](#configuration-configh)
10. [Build, Upload & Verify](#build-upload--verify)
11. [Sensor Calibration (Bucket Test)](#sensor-calibration-bucket-test)
12. [OTA Firmware Updates](#ota-firmware-updates)
13. [Troubleshooting Common Issues](#troubleshooting-common-issues)

---

## Hardware Overview

### Room ESP32s (×3)

| Component | Qty | Key Specs |
|---|-----|---|
| **ESP32 Dev Module** | 3 | 38-pin, CP2102/CH340, 4 MB Flash |
| **ESP32 Expansion Board** | 3 | Screw terminals for all GPIOs |
| **MFRC522 RFID Reader** | 3 | SPI, 13.56MHz, reads Mifare Classic |
| **YF-S201 Flow Sensor** | 3 | 1/2" NPT, Hall effect, 5V, ~450 pulses/L |
| **Fotek 40A SSR** | 3 | DC control, powers room electrical line |
| **1-ch Relay 10A** | 3 | Optocoupler, controls solenoid valve |
| **Solenoid Valve 1/2" NC** | 3 | 12V DC, normally closed |

| Room ESP32 | Room | Flow GPIO | SSR GPIO | Relay GPIO | RFID Interface |
|---|---|---|---|---|---|
| #1 | Bathroom | GPIO 26 | GPIO 27 | GPIO 25 | SPI (5,18,23,19 + RST 21) |
| #2 | Kitchen | GPIO 26 | GPIO 27 | GPIO 25 | SPI (5,18,23,19 + RST 21) |
| #3 | Shower | GPIO 26 | GPIO 27 | GPIO 25 | SPI (5,18,23,19 + RST 21) |

### Main ESP32

| Component | Qty | Key Specs |
|---|-----|---|
| **ESP32 Dev Module** | 1 | 38-pin, CP2102/CH340, 4 MB Flash |
| **ESP32 Expansion Board** | 1 | Screw terminals for all GPIOs |

| Component | Interface | Notes |
|---|---|---|
| YF-S201 Flow Sensor (calibrated) | Pulse | GPIO 34 — accurate metering |
| 2CH Relay with Optocoupler | Digital | IN1 → GPIO 19 (Solenoid 1), IN2 → GPIO 18 (Solenoid 2) |
| Solenoid Valve ×2 | Via 2CH relay | 12V NC — centralized at main |
| Reset Button | Digital | GPIO 27 — resets WiFi credentials |
| USB Serial | CDC/ACM | Debug / firmware upload only |
| Built-in LED | GPIO 2 | Status indication |

> **Note:** Main ESP32 has no SSR — room power SSRs live on the room ESP32s. Each room controls its own solenoid via its 1-ch relay (GPIO 25); the main ESP32 drives the 2 centralized valves via the 2CH relay.

---

## Arduino IDE Installation

### Method: `pip install arduino` (Recommended)

```bash
# 1. Update system
sudo apt update && sudo apt full-upgrade -y

# 2. Install pip if needed
sudo apt install -y python3-pip

# 3. Install Arduino IDE (includes Arduino CLI + IDE 2.x)
pip install arduino

# 4. Verify
arduino --version
# Arduino IDE 2.3.x
```

### Launch

```bash
# From terminal
arduino

# Or Applications Menu → Programming → Arduino IDE 2
```

---

## ESP32 Board Support Configuration

### 1. Open Preferences
**File → Preferences** (`Ctrl+,`)

### 2. Add Board Manager URL
In **Additional Boards Manager URLs**, paste:
```
https://raw.githubusercontent.com/espressif/arduino-esp32/gh-pages/package_esp32_index.json
```
Click **OK**.

> 📸 **Screenshot Placeholder:** *Arduino IDE Preferences dialog with ESP32 URL in Additional Boards Manager URLs field*

### 3. Install ESP32 Core
**Tools → Board → Boards Manager...** (`Ctrl+Shift+B`)
1. Search: **esp32**
2. Click **Install** on **"esp32 by Espressif Systems"** (latest version)
3. Wait for ~200 MB download (toolchain, libraries, examples)

> 📸 **Screenshot Placeholder:** *Boards Manager showing "esp32 by Espressif Systems" installing with progress bar*

### 4. Select Your Board
**Tools → Board → ESP32 Arduino → ESP32 Dev Module**

| Setting | Value |
|---|---|
| **Board** | ESP32 Dev Module |
| **Upload Speed** | 921600 |
| **CPU Frequency** | 240 MHz (WiFi/BT) |
| **Flash Mode** | QIO |
| **Flash Size** | 4 MB (32 Mb) |
| **Partition Scheme** | Default 4MB with spiffs (1.2MB APP/1.5MB SPIFFS) |
| **Core Debug Level** | None |
| **PSRAM** | Disabled |

> ⚠️ **Critical:** Selecting **ESP32 Dev Module** ensures correct pin mapping for 38-pin board. The GPIO pins in `config.h` (26 flow, 27 SSR, 25 solenoid relay) match this board definition.

---

## ArduinoJson Library Setup

### Install via Library Manager

1. **Tools → Manage Libraries...** (`Ctrl+Shift+I`)
2. Search: **ArduinoJson**
3. Click **Install** on **"ArduinoJson by Benoit Blanchon"** (v7.x+)
4. Wait for installation

> 📸 **Screenshot Placeholder:** *Library Manager showing "ArduinoJson" by Benoit Blanchon installing*

### Version Note
- **ArduinoJson v7+** uses `JsonDocument` (replaces `StaticJsonDocument`/`DynamicJsonDocument`)
- Memory efficient, zero-copy parsing
- No separate `Firebase-ESP-Client` needed — we use plain USB Serial

---

## Firmware Architecture & File Structure

```
src/
├── water-meter.ino          # Main sketch (setup + loop)
├── config.h                 # ALL parameters (WiFi, sensors, timing)
├── config.example.h         # Template for git (copy to config.h)
├── sensor_manager.h         # Single ISR pulse counter + flow calc
├── flow_sensor.h            # Single sensor class
├── serial_comm.h            # USB Serial JSON sender/receiver
├── local_rules.h            # Offline leak detection
├── wifi_manager.h           # WiFi connect + auto-reconnect (for OTA)
├── data_logger.h            # SPIFFS fallback logging
├── ntp_sync.h               # NTP time sync for timestamps
├── ota_updater.h            # OTA firmware updates via WiFi
└── led_indicator.h          # Built-in LED (GPIO 2) status patterns
```

### Key Design Principles

- **Non-blocking loop** — `delay(100)` max, all operations poll-based
- **ISR-safe** — Pulse counters use `volatile` + `IRAM_ATTR` + 5ms debounce
- **Modular** — Each subsystem in own header, single responsibility
- **Fail-safe** — SPIFFS logging when USB disconnected
- **Observable** — LED patterns indicate state at a glance

---

## Main Loop & Sensor Management

### Main Loop (`water-meter.ino`)

```cpp
#include <Arduino.h>
#include "config.h"
#include "sensor_manager.h"
#include "serial_comm.h"
#include "local_rules.h"
#include "wifi_manager.h"
#include "data_logger.h"
#include "led_indicator.h"
#include "ota_updater.h"
#include "ntp_sync.h"

SensorManager sensorManager;
SerialComm serialComm;
LocalRules localRules;
WiFiManager wifiManager;
DataLogger dataLogger;
LEDIndicator ledIndicator;
OTAUpdater otaUpdater;
NTPSync ntpSync;

unsigned long lastSend = 0;
unsigned long lastStatus = 0;

void setup() {
    Serial.begin(921600);
    while (!Serial) delay(10);  // Wait for USB CDC
    
    // 1. Initialize sensors
    sensorManager.begin();
    
    // 2. Initialize WiFi (for OTA + NTP only)
    wifiManager.begin();
    
    // 3. Sync time via NTP
    ntpSync.begin();
    
    // 4. Initialize SPIFFS logger
    dataLogger.begin();
    
    // 5. Initialize OTA
    otaUpdater.begin();
    
    // 6. LED ready pattern
    ledIndicator.setPattern(LED_READY);
    
    Serial.println("{\"status\":\"ready\",\"device_id\":\"" DEVICE_ID "\",\"firmware\":\"" FIRMWARE_VERSION "\"}");
}

void loop() {
    // 1. Check WiFi + OTA (non-blocking)
    wifiManager.loop();
    otaUpdater.loop();
    
    // 2. Check for incoming commands from Firebase (via mobizt stream)
    if (Serial.available()) {
        serialComm.handleCommand();
    }
    
    // 3. Read all pulse counters (non-blocking)
    sensorManager.readAll();
    
    // 4. Periodic sensor data send (every 5 sec)
    if (millis() - lastSend >= SEND_INTERVAL_MS) {
        sendSensorData();
        lastSend = millis();
    }
    
    // 5. Local leak rules (runs every cycle)
    localRules.checkAll();
    
    // 6. Status LED update
    ledIndicator.update();
    
    // 7. Periodic status heartbeat (every 30 sec)
    if (millis() - lastStatus >= 30000) {
        serialComm.sendStatus();
        lastStatus = millis();
    }
    
    delay(100);  // Non-blocking cycle
}
```

### Sensor Manager (`sensor_manager.h`)

```cpp
// Manages 4 flow sensors with ISR pulse counting
class SensorManager {
public:
    void begin() {
        for (int i = 0; i < 4; i++) {
            pinMode(sensorPins[i], INPUT);
            attachInterruptArg(digitalPinToInterrupt(sensorPins[i]),
                               pulseISR, (void*)i, RISING);
        }
    }

    void readAll() {
        // Atomic read of pulse counters
        noInterrupts();
        for (int i = 0; i < 4; i++) {
            pulseCountLocal[i] = pulseCount[i];
            pulseCount[i] = 0;  // Reset for next interval
        }
        interrupts();
        
        // Calculate flow rate per sensor
        float intervalSec = SEND_INTERVAL_MS / 1000.0;
        for (int i = 0; i < 4; i++) {
            flowRate[i] = (pulseCountLocal[i] * 60.0) / (ppl[i] * intervalSec);
            totalVolume[i] += pulseCountLocal[i] / ppl[i];
        }
    }

    float getFlowRate(int index) { return flowRate[index]; }
    float getVolume(int index) { return totalVolume[index]; }
    uint32_t getPulses(int index) { return pulseCountLocal[index]; }

private:
    static void IRAM_ATTR pulseISR(void* arg) {
        int idx = (int)arg;
        uint32_t now = millis();
        if (now - lastPulseTime[idx] > 5) {  // 5ms debounce
            pulseCount[idx]++;
            lastPulseTime[idx] = now;
        }
    }

    const uint8_t sensorPin = PIN_SENSOR;
    float ppl = PPL_SENSOR;  // From config.h
    
    volatile uint32_t pulseCount[4] = {0};
    volatile uint32_t lastPulseTime[4] = {0};
    uint32_t pulseCountLocal[4] = {0};
    float flowRate[4] = {0};
    float totalVolume[4] = {0};
};
```

---

## USB Serial Communication

### Serial Protocol

**Baud Rate:** 921600  
**Format:** JSON Lines (newline-delimited JSON)  
**Encoding:** UTF-8

### Room → Main (ESP-NOW, every 5 sec)

```json
{"room_id":1,"ts":1703123456789,"pulses":127,"flow_rate_lpm":2.34,"volume_ml":456,"leak_alert":false}
```

### Main ESP32 → Firebase RTDB (WiFi + mobizt)

```json
{"device_id":"wmldad-main","ts":1703123456789,"rooms":[{"room_id":1,"flow_rate_lpm":2.34},{"room_id":2,"flow_rate_lpm":0.0},{"room_id":3,"flow_rate_lpm":1.12}]}
```

### Alert Frame (leak detected)

```json
{"device_id":"wmldad-main","ts":1703123456789,"type":"alert","level":"major_leak","room_id":2,"flow_rate_lpm":15.2,"message":"Major leak in Kitchen"}
```

### Command Frame (Firebase → Main ESP32 via mobizt stream)

```json
{"cmd":"shutoff","room_id":1}
{"cmd":"calibrate","room_id":2,"ppl":450}
{"cmd":"reset_counters"}
```

### Serial Communication Handler (`serial_comm.h`)

```cpp
#include <ArduinoJson.h>

class SerialComm {
public:
    void sendSensorData(const SensorManager& sensors, const char* deviceId) {
        StaticJsonDocument<256> doc;
        doc["device_id"] = deviceId;
        doc["ts"] = millis();  // Use NTP time if available
        
        const char* sensorNames[4] = {"inlet", "bidet", "kitchen", "bathroom_shower"};
        const uint8_t sensorPin = PIN_SENSOR;
        
        for (int i = 0; i < 4; i++) {
            JsonObject s = doc[sensorNames[i]].to<JsonObject>();
            s["gpio"] = sensorPins[i];
            s["pulses"] = sensors.getPulses(i);
            s["flow_rate_lpm"] = round(sensors.getFlowRate(i) * 100) / 100.0;
            s["volume_ml"] = round(sensors.getVolume(i) * 1000);
        }
        
        serializeJson(doc, Serial);
        Serial.println();  // Newline delimiter
    }
    
    void sendAlert(int sensorIdx, const char* level, float flowRate, int duration, const char* msg) {
        StaticJsonDocument<256> doc;
        doc["device_id"] = DEVICE_ID;
        doc["ts"] = millis();
        doc["type"] = "alert";
        doc["level"] = level;
        doc["sensor"] = sensorIdx;
        doc["flow_rate_lpm"] = flowRate;
        doc["duration_sec"] = duration;
        doc["message"] = msg;
        
        serializeJson(doc, Serial);
        Serial.println();
    }
    
    void sendStatus() {
        StaticJsonDocument<256> doc;
        doc["device_id"] = DEVICE_ID;
        doc["ts"] = millis();
        doc["type"] = "status";
        doc["uptime_sec"] = millis() / 1000;
        doc["free_heap"] = ESP.getFreeHeap();
        doc["wifi_rssi"] = WiFi.RSSI();
        doc["sensors_ok"] = true;
        
        serializeJson(doc, Serial);
        Serial.println();
    }
    
    void handleCommand() {
        String line = Serial.readStringUntil('\n');
        line.trim();
        if (line.length() == 0) return;
        
        StaticJsonDocument<256> cmdDoc;
        DeserializationError err = deserializeJson(cmdDoc, line);
        if (err) return;
        
        const char* cmd = cmdDoc["cmd"];
        if (!cmd) return;
        
        StaticJsonDocument<128> resp;
        resp["cmd"] = cmd;
        resp["status"] = "ok";
        
        if (strcmp(cmd, "calibrate") == 0) {
            sensorManager.startCalibration();
            resp["msg"] = "Calibration mode: run known volume";
        } else if (strcmp(cmd, "reboot") == 0) {
            resp["msg"] = "Rebooting...";
            serializeJson(resp, Serial);
            Serial.println();
            ESP.restart();
        } else if (strcmp(cmd, "reset_counters") == 0) {
            for (int i = 0; i < 4; i++) sensorManager.resetVolume(i);
            resp["msg"] = "Counters reset";
        } else if (strcmp(cmd, "set_ppl") == 0) {
            int sensor = cmdDoc["sensor"] | 0;
            float ppl = cmdDoc["ppl"] | 450.0;
            sensorManager.setPPL(sensor, ppl);
            resp["msg"] = "PPL updated (not persistent)";
        }
        
        serializeJson(resp, Serial);
        Serial.println();
    }
};
```

---

## Local Leak Detection Rules (Offline Fallback)

Runs on ESP32 locally — critical for immediate alerting, even without WiFi.

```cpp
// local_rules.h — Runs on each room ESP32
// Handles RFID session + smart solenoid + leak detection:

class LocalRules {
public:
    void checkAll(float flowRate, float continuousTime) {
        unsigned long now = millis();
        
        // === SMART SOLENOID CONTROL ===
        // Only energize solenoid when water is actually flowing
        // This prevents solenoid overheating from continuous energization
        
        if (sessionActive) {
            if (flowRate > 0.01) {
                // Water flowing — keep solenoid ON
                lastFlowTime = now;
                digitalWrite(PIN_RELAY, HIGH);
            } else if (now - lastFlowTime > SOLENOID_OFF_DELAY_MS) {
                // No flow for N sec — turn solenoid OFF (prevent heating)
                digitalWrite(PIN_RELAY, LOW);
            }
            
            // Session timeout (no activity for X min)
            if (now - lastFlowTime > SESSION_TIMEOUT_MS) {
                endSession();
            }
        }
        
        // ============================================
        // === LEAK DETECTION RULES ===
        // ============================================
        
        // RULE 1: NO RFID + FLOW DETECTED = LEAK
        // No customer in room (no valid session) but water is flowing
        // This is the most common leak scenario: broken pipe, stuck valve, etc.
        if (!sessionActive && flowRate > 0.01) {
            triggerAlert("no_session_flow");  // Critical: unknown water flow
            emergencyShutoff();
        }
        
        // RULE 2: SESSION ENDED + FLOW CONTINUES = LEAK
        // Customer left (SSR OFF) but water still flowing
        // Solenoid should be closed — if flow persists, solenoid is stuck open
        if (!sessionActive && !solenoidOn && flowRate > 0.01) {
            triggerAlert("post_session_flow");  // Solenoid stuck open
            emergencyShutoff();
        }
        
        // RULE 3: SOLENOID OFF + FLOW DETECTED = LEAK
        // Solenoid is commanded OFF but flow sensor still reads water
        // Means solenoid is physically stuck open or pipe burst downstream
        if (!solenoidOn && flowRate > 0.01) {
            triggerAlert("solenoid_stuck_open");  // Critical hardware failure
            emergencyShutoff();
        }
        
        // RULE 4: CONTINUOUS FLOW > 30 MIN = STUCK VALVE / RUNNING TOILET
        // Even with active session, flowing for 30+ min is abnormal
        if (flowRate > 0.01 && continuousTime > 30 * 60) {
            triggerAlert("continuous_flow");
            emergencyShutoff();
        }
        
        // RULE 5: DRIP LEAK (0.1–0.5 L/min for > 5 MIN)
        // Slow, steady trickle — dripping faucet, loose fitting
        if (flowRate > 0.1 && flowRate < 0.5 && continuousTime > 5 * 60) {
            triggerAlert("drip_leak");
            emergencyShutoff();
        }
        
        // RULE 6: NIGHT FLOW (22:00–05:00) WITH NO SESSION = SUSPICIOUS
        // Water usage during sleeping hours with no authorized user
        if (!sessionActive && isNightTime() && flowRate > 0.01) {
            triggerAlert("night_flow");  // Possible unauthorized use or leak
            emergencyShutoff();
        }
    }
    
    void startSession() {
        sessionActive = true;
        lastFlowTime = millis();
        digitalWrite(PIN_SSR, HIGH);        // Room powered ON (electrical line)
        digitalWrite(PIN_RELAY, HIGH);      // Solenoid ON (water flows)
        solenoidOn = true;
    }
    
    void endSession() {
        sessionActive = false;
        digitalWrite(PIN_RELAY, LOW);       // Solenoid OFF first (stop water)
        digitalWrite(PIN_SSR, LOW);         // Room powered OFF
        solenoidOn = false;
    }
    
    void emergencyShutoff() {
        digitalWrite(PIN_RELAY, LOW);       // Solenoid OFF (stop water)
        digitalWrite(PIN_SSR, LOW);         // Room OFF
        sessionActive = false;
        solenoidOn = false;
    }

    void triggerAlert(const char* type) {
        dataLogger.logAlert(type, ROOM_ID);
        ledIndicator.setPattern(LED_FAST_BLINK);
        // Send via ESP-NOW to main ESP32 (with leak_alert flag)
    }
};
```

> **6 Leak Detection Rules:**
> 1. **No RFID + Flow** = No customer but water flowing → CRITICAL leak
> 2. **Session ended + Flow** = Customer left but water continues → Solenoid stuck open
> 3. **Solenoid OFF + Flow** = Valve commanded closed but flow persists → Hardware failure
> 4. **Continuous flow > 30 min** = Stuck valve / running toilet
> 5. **Drip (0.1–0.5 L/min) > 5 min** = Slow leak from loose fitting / dripping faucet
> 6. **Night flow (22:00–05:00) no session** = Suspicious unauthorized usage or leak
>
> **All leak rules trigger emergency shutoff:** SSR OFF + Solenoid OFF.
> **All alerts sent via ESP-NOW** to main ESP32 → Firebase RTDB → Next.js dashboard notification.

---

## Configuration (`config.h`)

```cpp
// config.h — ALL parameters in one place
// Copy config.example.h to config.h and fill in your values
// For ROOM ESP32s: set ROOM_ID and PIN_SENSOR
// For MAIN ESP32: set IS_MAIN = true and configure WiFi/Firebase + central relay pins

#pragma once

// ===== Device Identity =====
#define DEVICE_ID        "wmldad-room1"   // wmldad-room2, wmldad-room3, wmldad-main
#define FIRMWARE_VERSION "v4.0.0-espnow"
#define ROOM_ID          1                // 1=bathroom, 2=kitchen, 3=shower
#define IS_MAIN          false            // true for main ESP32

// ===== WiFi (main ESP32 connects to WiFi + Firebase) =====
#define WIFI_SSID        "YourWiFiSSID"
#define WIFI_PASSWORD    "YourWiFiPassword"

// ===== Firebase (main ESP32 only — mobizt Firebase-ESP-Client) =====
// Get these from Firebase Console → Project Settings → General
#define FIREBASE_API_KEY "YOUR_FIREBASE_API_KEY"
#define FIREBASE_DATABASE_URL "https://your-project.firebaseio.com"
// Optional: Firebase Auth (if RTDB rules require auth)
#define FIREBASE_USER_EMAIL "your@email.com"
#define FIREBASE_USER_PASSWORD "your-password"

// ===== Sensor Calibration (PPL = Pulses Per Liter) =====
// UPDATE AFTER BUCKET TEST!
#define PPL_SENSOR       450

// ===== Sensor Pin (all room ESP32s use GPIO 26) =====
#define PIN_SENSOR       26

// ===== Main ESP32 Peer MAC (for ESP-NOW) =====
// Update with your main ESP32's MAC address
#define MAIN_ESP_MAC     {0xAA, 0xBB, 0xCC, 0xDD, 0xEE, 0xFF}

// ===== RFID Reader (MFRC522 SPI) =====
#define RFID_SS_PIN     5              // SDA/NSS
#define RFID_RST_PIN    21
// SPI: SCK=18, MOSI=23, MISO=19 (default ESP32 SPI)

// ===== SSR Relay Pin (per room — powers room electrical line) =====
#define PIN_SSR          27            // HIGH = room powered, LOW = room off

// ===== Solenoid Relay Pin (per room — 1-ch 10A relay controls solenoid) =====
#define PIN_RELAY        25            // HIGH = solenoid ON (water flows), LOW = shutoff
// Solenoid is ONLY energized when flow sensor detects water usage
// This prevents solenoid overheating from continuous energization
#define SOLENOID_OFF_DELAY_MS  5000    // Solenoid OFF after 5 sec no flow (prevent heating)
#define SESSION_TIMEOUT_MS  600000     // Session ends after 10 min no flow

// ===== Timing =====
#define SEND_INTERVAL_MS 5000            // ESP-NOW send every 5 sec
#define CALIBRATION_TIMEOUT_MS 300000    // 5 min calibration window

// ===== Local Leak Thresholds =====
#define CONTINUOUS_FLOW_MIN 30           // Minutes — stuck valve / running toilet
#define DRIP_MIN_RATE 0.1                // L/min
#define DRIP_MAX_RATE 0.5                // L/min
#define DRIP_MIN_TIME 5                  // Minutes — drip detection window
#define NIGHT_START_HOUR 22              // 10 PM — night flow detection starts
#define NIGHT_END_HOUR 5                 // 5 AM — night flow detection ends
#define MIN_FLOW_THRESHOLD 0.01          // L/min — minimum detectable flow

// ===== Main ESP32 Pins (IS_MAIN = true) =====
#define PIN_SENSOR_MAIN       34   // Calibrated YF-S201 flow sensor (accurate metering)
#define PIN_CENTRAL_RELAY1    19   // 2CH relay IN1 — central Solenoid 1
#define PIN_CENTRAL_RELAY2    18   // 2CH relay IN2 — central Solenoid 2
#define PIN_RESET_BUTTON      27   // Arcade button — resets WiFi credentials

// ===== SPIFFS Logging =====
#define MAX_OFFLINE_LOGS 500
```

---

## Build, Upload & Verify

### 1. Verify (Compile)
**Sketch → Verify/Compile** (`Ctrl+R`)
- Should compile with 0 errors, ~250 KB flash usage

### 2. Select Port
**Tools → Port** → `/dev/ttyUSB0` (Linux) or `COMx` (Windows)

### 3. Upload
**Sketch → Upload** (`Ctrl+U`)

#### If Upload Fails (Bootloader Mode):
1. Hold **BOOT** button
2. Press and release **EN** (Reset) while holding BOOT
3. Release **BOOT**
4. Retry Upload (`Ctrl+U`)

### 4. Verify via Serial Monitor
**Tools → Serial Monitor** (`Ctrl+Shift+M`) → **921600 baud**

**Expected Output:**
```
// Room ESP32:
{"status":"ready","device_id":"wmldad-room1","firmware":"v4.0.0-espnow"}
{"room_id":1,"ts":123456,"pulses":127,"flow_rate_lpm":2.34,"volume_ml":456,"leak_alert":false}

// Main ESP32:
{"status":"ready","device_id":"wmldad-main","firmware":"v4.0.0-espnow"}
{"rooms":[{"room_id":1,"flow_rate_lpm":2.34},{"room_id":2,"flow_rate_lpm":0.0},{"room_id":3,"flow_rate_lpm":1.12}]}
```

---

## Sensor Calibration (Bucket Test)

> **Importance:** Accurate calibration is critical for leak detection. An uncalibrated sensor with ±10% error will trigger false positives or miss real leaks.

### Quick Calibration (Bucket Test)

1. **Prepare:** Get a 5L graduated container
2. **Connect:** Run water from faucet through the inlet sensor into the container
3. **Open:** Turn on faucet at medium flow
4. **Collect:** Exactly 5 liters
5. **Read:** Get pulse count from Serial Monitor (command: `status` or watch pulses field)
6. **Calculate:**
   ```
   Actual PPL = Total Pulse Count ÷ 5
   ```
7. **Update:** Change `PPL_SENSOR` in `config.h`
8. **Repeat** for each sensor (move sensor to each fixture line)

### Target
< 3% error per sensor. Typical YF-S201: 400–480 PPL.

---

## OTA Firmware Updates

Even though primary communication is USB Serial, WiFi + OTA allows remote firmware updates without physical access.

### OTA Updater (`ota_updater.h`)

```cpp
#include <ArduinoOTA.h>

class OTAUpdater {
public:
    void begin() {
        ArduinoOTA.setHostname(DEVICE_ID);
        ArduinoOTA.setPassword(OTA_PASSWORD);  // Define in config.h
        
        ArduinoOTA.onStart([]() {
            String type = (ArduinoOTA.getCommand() == U_FLASH) ? "sketch" : "filesystem";
            Serial.println("{\"ota\":\"start\",\"type\":\"" + type + "\"}");
        });
        ArduinoOTA.onEnd([]() {
            Serial.println("{\"ota\":\"end\"}");
        });
        ArduinoOTA.onProgress([](unsigned int progress, unsigned int total) {
            Serial.printf("{\"ota\":\"progress\",\"pct\":%u}\n", (progress / (total / 100)));
        });
        ArduinoOTA.onError([](ota_error_t error) {
            Serial.printf("{\"ota\":\"error\",\"code\":%u}\n", error);
        });
        
        ArduinoOTA.begin();
    }
    
    void loop() {
        ArduinoOTA.handle();
    }
};
```

### Trigger OTA Update
```bash
# From any computer on same network
arduino-cli upload -p wmldad-main.local -b esp32:esp32:esp32 --port network
# Or use Arduino IDE: Tools → Port → Network ports → wmldad-main
```

---

## Troubleshooting Common Issues

| Issue | Cause | Fix |
|---|---|-----|
| **No Serial output** | Baud rate mismatch | Set Serial Monitor to **921600** |
| **Upload fails** | Not in bootloader | Hold BOOT → Press EN → Release BOOT → Upload |
| **JSON parse errors** | Buffer overflow | Increase `StaticJsonDocument` size |
| **Flow rate reads 0** | Wrong GPIO pin | Verify pin in `config.h` matches wiring |
| **WiFi won't connect** | Wrong credentials | Check `WIFI_SSID`/`WIFI_PASSWORD` in `config.h` |
| **OTA not showing** | mDNS not working | Use IP address; install Bonjour on Windows |
| **SPIFFS not mounting** | Partition scheme | Use "Default 4MB with spiffs" partition |
| **Pulses too high/low** | Uncalibrated | Run bucket test, update PPL in `config.h` |

---

## LED Indicator Reference

| LED Pattern | Meaning |
|---|---|
| Solid green | Normal operation, all OK |
| Blink green (1s) | WiFi connecting |
| Blink blue (fast) | Transmitting serial data |
| Solid yellow | Minor leak detected (alert) |
| Solid red | Major leak detected (critical) |
| Red flash | Emergency — urgent action needed |
| Blink white (3x + pause) | Successful data send |
| Blink red (5x + pause) | Send failed / error |
| Off | Deep sleep or no power |

---

## Checklist Before Panicking

- [ ] Is ESP32 getting power? (LED on?)
- [ ] Is USB cable a **data cable**? (not charge-only)
- [ ] Is Serial Monitor baud set to **921600**?
- [ ] Is the flow sensor arrow pointing **WITH** the water flow?
- [ ] Are WiFi SSID and password correct? (for OTA only)
- [ ] Is `PPL` calibrated for each sensor?
- [ ] Is ArduinoJson v7+ installed?
- [ ] Is board set to **ESP32 Dev Module**?

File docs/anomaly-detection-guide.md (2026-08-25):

# Anomaly Detection Guide — TapFlow

> **Purpose:** Detect unusual water usage patterns across rooms using statistical and rule-based methods on ESP32 firmware + Firebase cloud + Next.js dashboard.
> **Builds on:** [system-architecture.md](./system-architecture.md), [block-diagram.md](./block-diagram.md)
> **Feeds into:** [leak-detection-advanced-guide.md](./leak-detection-advanced-guide.md), [web-dashboard-alerts-guide.md](./web-dashboard-alerts-guide.md)

---

## Table of Contents

1. [What Is Anomaly Detection?](#1-what-is-anomaly-detection)
2. [Detection Layers (ESP32 + Cloud + Dashboard)](#2-detection-layers-esp32--cloud--dashboard)
3. [Algorithms](#3-algorithms)
4. [ESP32 Module: `anomaly_detector.h`](#4-esp32-module-anomaly_detectorh)
5. [Firebase RTDB Data Structure](#5-firebase-rtdb-data-structure)
6. [Main ESP32 → Firebase Push Format](#6-main-esp32--firebase-push-format)
7. [Alert Severity Levels](#7-alert-severity-levels)
8. [Configuration Thresholds](#8-configuration-thresholds)
9. [Integration with Leak Detection](#9-integration-with-leak-detection)
10. [Validation Checklist](#10-validation-checklist)

---

## 1. What Is Anomaly Detection?

Anomaly detection identifies **unusual patterns** in water usage that are not necessarily leaks but deviate from normal behavior. While **leak detection** (see [leak-detection-advanced-guide.md](./leak-detection-advanced-guide.md)) handles critical failures, anomaly detection catches **softer signals** that warrant investigation.

| Detection Type | Response | Example |
|---|---|---|
| **Leak Detection** | Emergency shutoff + alert | Solenoid stuck open, no-RFID flow |
| **Anomaly Detection** | Warning notification + logging | Sudden flow spike, unusual night usage, consumption drift |

---

## 2. Detection Layers (ESP32 + Cloud + Dashboard)

```
┌─────────────────────────────────────────────────────────────────────┐
│                     ANOMALY DETECTION LAYERS                        │
├─────────────────────────────────────────────────────────────────────┤
│                                                                     │
│  LAYER 1: Room ESP32 (real-time, offline-capable)                  │
│  ┌───────────────────────────────────────────────────────────────┐  │
│  │  • Rate-of-change detection (spike in flow rate)             │  │
│  │  • Burst detection (short high-flow pulses)                  │  │
│  │  • Baseline deviation (current vs. rolling average)          │  │
│  │  • Runs every cycle (~100ms), sends flags via ESP-NOW        │  │
│  └───────────────────────────────────────────────────────────────┘  │
│                              │                                      │
│                              ▼                                      │
│  LAYER 2: Main ESP32 (aggregation + cross-room checks)             │
│  ┌───────────────────────────────────────────────────────────────┐  │
│  │  • Mass balance check (inlet vs. sum of rooms)               │  │
│  │  • Cross-room correlation (multiple rooms active = normal)   │  │
│  │  • Time-pattern analysis (night usage, weekend patterns)     │  │
│  │  • Aggregates room flags + own sensor → pushes to Firebase   │  │
│  └───────────────────────────────────────────────────────────────┘  │
│                              │                                      │
│                              ▼                                      │
│  LAYER 3: Firebase Cloud (history + trend analysis)                │
│  ┌───────────────────────────────────────────────────────────────┐  │
│  │  • Historical baseline computation (7-day rolling average)   │  │
│  │  • Trend detection (gradual consumption increase)            │  │
│  │  • Anomaly scoring (weighted combination of signals)         │  │
│  │  • Stores alerts, scores, and baselines for dashboard        │  │
│  └───────────────────────────────────────────────────────────────┘  │
│                              │                                      │
│                              ▼                                      │
│  LAYER 4: Next.js Dashboard (visualization + user alerts)          │
│  ┌───────────────────────────────────────────────────────────────┐  │
│  │  • Real-time anomaly feed (Firebase onValue listener)        │  │
│  │  • Trend charts (hourly/daily/weekly consumption)            │  │
│  │  • Anomaly score gauge + historical log                      │  │
│  │  • User-configurable threshold overrides                     │  │
│  └───────────────────────────────────────────────────────────────┘  │
│                                                                     │
└─────────────────────────────────────────────────────────────────────┘
```

---

## 3. Algorithms

### 3.1 Rate-of-Change Detection (Room ESP32)

Detects **sudden spikes** in flow rate between consecutive readings.

```
┌─────────────────────────────────────────────────────────────────┐
│  ALGORITHM: Rate-of-Change                                      │
│  ─────────────────────────────────────────────────────────────  │
│                                                                 │
│  Inputs:                                                        │
│    flow_rate_now    — current flow rate (L/min)                 │
│    flow_rate_prev   — previous flow rate (L/min)                │
│    dt               — time since last reading (seconds)         │
│                                                                 │
│  Computation:                                                   │
│    delta    = flow_rate_now - flow_rate_prev                    │
│    rate     = delta / dt                                        │
│                                                                 │
│  Thresholds:                                                    │
│    SPIKE    = rate > 5.0 L/min/sec   → ANOMALY: sudden spike   │
│    DROP     = rate < -5.0 L/min/sec  → ANOMALY: sudden drop    │
│                                                                 │
│  Rationale: Normal faucet opening reaches steady state in       │
│  ~2-3 sec. Faster changes suggest valve malfunction or pipe     │
│  burst.                                                         │
└─────────────────────────────────────────────────────────────────┘
```

**ESP32 implementation sketch:**

```cpp
// In anomaly_detector.h
struct RateOfChangeResult {
    bool spikeDetected;
    bool dropDetected;
    float rate;          // L/min/sec
    float delta;         // L/min
};

RateOfChangeResult checkRateOfChange(float flowNow, float flowPrev, unsigned long dtMs) {
    RateOfChangeResult result;
    float dt = dtMs / 1000.0;
    if (dt < 0.1) dt = 0.1;  // prevent division by near-zero

    result.delta = flowNow - flowPrev;
    result.rate = result.delta / dt;
    result.spikeDetected = (result.rate > SPIKE_THRESHOLD);   // > 5.0 L/min/sec
    result.dropDetected  = (result.rate < -SPIKE_THRESHOLD);  // < -5.0 L/min/sec
    return result;
}
```

---

### 3.2 Baseline Deviation Detection (Room ESP32)

Compares current flow rate against a **rolling average** maintained on the ESP32.

```
┌─────────────────────────────────────────────────────────────────┐
│  ALGORITHM: Baseline Deviation (Z-Score)                        │
│  ─────────────────────────────────────────────────────────────  │
│                                                                 │
│  Maintains:                                                     │
│    baseline[WINDOW_SIZE]  — circular buffer of last N readings  │
│    baseline_mean          — mean of buffer                      │
│    baseline_std           — standard deviation of buffer        │
│                                                                 │
│  Computation:                                                   │
│    z_score = (flow_rate_now - baseline_mean) / baseline_std    │
│                                                                 │
│  Thresholds:                                                    │
│    |z_score| > 3.0  → ANOMALY: significant deviation           │
│    |z_score| > 2.0  → WARNING: notable deviation               │
│                                                                 │
│  Window: 60 readings (5 min at 5-sec intervals)                │
│  Warmup: First 12 readings ignored (build baseline)            │
└─────────────────────────────────────────────────────────────────┘
```

**ESP32 implementation sketch:**

```cpp
// In anomaly_detector.h
#define BASELINE_WINDOW 60    // 5 min at 5-sec intervals
#define BASELINE_WARMUP 12    // 60 sec warmup
#define ZSCORE_ANOMALY  3.0
#define ZSCORE_WARNING  2.0

class BaselineTracker {
    float buffer[BASELINE_WINDOW];
    int index = 0;
    int count = 0;
    float mean = 0;
    float variance = 0;

public:
    void update(float value) {
        if (count < BASELINE_WINDOW) {
            buffer[count] = value;
            count++;
        } else {
            buffer[index] = value;
            index = (index + 1) % BASELINE_WINDOW;
        }
        // Recompute mean and variance
        float sum = 0, sumSq = 0;
        for (int i = 0; i < count; i++) {
            sum += buffer[i];
            sumSq += buffer[i] * buffer[i];
        }
        mean = sum / count;
        variance = (sumSq / count) - (mean * mean);
    }

    float getZScore(float value) {
        if (count < BASELINE_WARMUP) return 0;  // not enough data
        float std = sqrt(max(variance, 0.001f));
        return (value - mean) / std;
    }

    bool isWarmedUp() { return count >= BASELINE_WARMUP; }
};
```

---

### 3.3 Burst Detection (Room ESP32)

Detects **short, high-flow pulses** that may indicate water hammer, valve chatter, or sensor noise.

```
┌─────────────────────────────────────────────────────────────────┐
│  ALGORITHM: Burst Detection                                     │
│  ─────────────────────────────────────────────────────────────  │
│                                                                 │
│  Tracks:                                                        │
│    burst_start      — timestamp when flow started               │
│    burst_volume     — cumulative volume during burst (ml)       │
│    burst_active     — boolean: currently in a burst             │
│                                                                 │
│  Logic:                                                         │
│    IF flow > BURST_MIN_RATE (2.0 L/min)                        │
│       AND burst was not active before:                          │
│         → Start burst timer, set burst_active = true            │
│                                                                 │
│    IF flow < BURST_MIN_RATE                                     │
│       AND burst was active:                                     │
│         → End burst. Check:                                     │
│           duration < BURST_MAX_DURATION (10 sec)                │
│           volume < BURST_MAX_VOLUME (200 ml)                    │
│           → ANOMALY: short burst detected                       │
│                                                                 │
│  Rationale: A burst < 10 sec and < 200 ml is too short for      │
│  normal use. Likely water hammer, valve chatter, or sensor      │
│  noise.                                                         │
└─────────────────────────────────────────────────────────────────┘
```

---

### 3.4 Time-Pattern Analysis (Main ESP32)

Detects usage at **unusual times** (not just night — also weekends, holidays, etc.).

```
┌─────────────────────────────────────────────────────────────────┐
│  ALGORITHM: Time-Pattern Analysis                               │
│  ─────────────────────────────────────────────────────────────  │
│                                                                 │
│  Time periods (configurable):                                   │
│    NIGHT:      22:00 – 05:00  (sleeping hours)                 │
│    MORNING:    05:00 – 08:00  (early risers)                   │
│    DAYTIME:    08:00 – 18:00  (work hours)                     │
│    EVENING:    18:00 – 22:00  (peak usage)                     │
│                                                                 │
│  Baselines per period (learned from history):                   │
│    avg_usage[period]    — average volume per period (L)         │
│    std_usage[period]    — standard deviation                    │
│                                                                 │
│  Detection:                                                     │
│    IF usage during current period > avg_usage + 2*std           │
│       → ANOMALY: usage exceeds expected for this time of day   │
│                                                                 │
│    IF usage during NIGHT period > 0 AND no RFID session         │
│       → ANOMALY: unauthorized night usage                      │
│                                                                 │
│  Main ESP32 stores period baselines in Firebase at midnight.    │
│  Cloud computes baselines from historical data.                 │
└─────────────────────────────────────────────────────────────────┘
```

---

### 3.5 Trend Detection (Firebase Cloud)

Detects **gradual increases** in consumption over days/weeks — a sign of slow leaks.

```
┌─────────────────────────────────────────────────────────────────┐
│  ALGORITHM: Trend Detection (Cloud-side)                        │
│  ─────────────────────────────────────────────────────────────  │
│                                                                 │
│  Data: Daily total volume per room (last 30 days)              │
│                                                                 │
│  Computation:                                                   │
│    Fit linear regression: volume = slope * day + intercept      │
│    slope > TREND_THRESHOLD (0.5 L/day increase)                │
│       → ANOMALY: gradual consumption increase                   │
│                                                                 │
│  Also check:                                                    │
│    Week-over-week comparison:                                   │
│       IF this_week_total > last_week_total * 1.5               │
│          → ANOMALY: 50%+ week-over-week increase               │
│                                                                 │
│  Runs daily via Firebase Cloud Function (or scheduled check    │
│  on Next.js dashboard load).                                    │
└─────────────────────────────────────────────────────────────────┘
```

---

### 3.6 Mass Balance Anomaly (Main ESP32)

Detects **unaccounted water** — water entering the system but not reaching any room.

```
┌─────────────────────────────────────────────────────────────────┐
│  ALGORITHM: Mass Balance                                        │
│  ─────────────────────────────────────────────────────────────  │
│                                                                 │
│  Inputs:                                                        │
│    inlet_volume   — calibrated sensor total (main ESP32)        │
│    room_volumes[] — uncalibrated sensor totals (room ESP32s)    │
│                                                                 │
│  Computation:                                                   │
│    expected = room_volumes[0] + room_volumes[1] + room_volumes[2]│
│    balance  = inlet_volume - expected                           │
│    balance_pct = (balance / inlet_volume) * 100                 │
│                                                                 │
│  Thresholds:                                                    │
│    balance_pct > 20%  → ANOMALY: hidden leak between main and  │
│                          rooms (pipe burst in wall)              │
│    balance_pct > 10%  → WARNING: investigate connections        │
│    balance_pct < -10% → ANOMALY: sensor calibration drift      │
│                                                                 │
│  Note: Room sensors are uncalibrated (±10-15% error), so       │
│  thresholds are set generously to avoid false positives.        │
│  Requires at least 5L total flow for meaningful comparison.     │
└─────────────────────────────────────────────────────────────────┘
```

---

## 4. ESP32 Module: `anomaly_detector.h`

### 4.1 Room ESP32 Anomaly Detector

Runs on each room ESP32. Lightweight — only statistical checks on local sensor data.

**Responsibilities:**
- Rate-of-change detection (spike/drop)
- Baseline deviation (z-score)
- Burst detection (short high-flow pulses)
- Exports anomaly flags via ESP-NOW payload

**Data flow:**

```
┌─────────────────────────────────────────────────────┐
│                 ROOM ESP32                           │
│                                                      │
│  Flow Sensor (GPIO 26)                              │
│       │                                              │
│       ▼                                              │
│  SensorManager.readAll()                            │
│       │                                              │
│       ├──► flowRate[0] ──► AnomalyDetector          │
│       │                        │                     │
│       │    ┌───────────────────┤                     │
│       │    │                   │                     │
│       │    ▼                   ▼                     │
│       │  RateOfChange     BaselineTracker           │
│       │  (spike/drop)     (z-score)                 │
│       │    │                   │                     │
│       │    ▼                   ▼                     │
│       │  burstTracker     zscore > 3.0?             │
│       │  (short pulses)      │                      │
│       │    │                 │                      │
│       │    ▼                 ▼                      │
│       │    └───── anomaly_flags ──────► ESP-NOW     │
│       │                              (to Main ESP32)│
│       │                                              │
│  LocalRules.checkAll()                              │
│       │                                              │
│       ▼                                              │
│  leak_alert flag (also sent via ESP-NOW)            │
│                                                      │
└─────────────────────────────────────────────────────┘
```

**ESP-NOW payload (room → main) — updated with anomaly flags:**

| Field | Type | Description |
|---|---|---|
| `room_id` | uint8_t | Room number (1-3) |
| `ts` | uint32_t | Timestamp (millis or NTP) |
| `pulses` | uint32_t | Pulse count this interval |
| `flow_rate_lpm` | float | Current flow rate (L/min) |
| `volume_ml` | uint32_t | Cumulative volume (ml) |
| `leak_alert` | bool | Leak detection flag (from local_rules) |
| `anomaly_spike` | bool | Rate-of-change spike detected |
| `anomaly_baseline` | bool | Z-score > 3.0 deviation |
| `anomaly_burst` | bool | Short burst detected |
| `anomaly_flags` | uint8_t | Bitmask: bit0=spike, bit1=baseline, bit2=burst |

---

### 4.2 Main ESP32 Anomaly Detector

Aggregates room anomaly flags and runs cross-room checks.

**Responsibilities:**
- Receive room anomaly flags via ESP-NOW
- Mass balance check (inlet vs. sum of rooms)
- Time-pattern analysis (night/weekend usage)
- Push aggregated anomaly data to Firebase

**Data flow:**

```
┌──────────────────────────────────────────────────────────────┐
│                      MAIN ESP32                               │
│                                                               │
│  ESP-NOW Receiver                                            │
│       │                                                       │
│       ├──► Room 1 data (pulses, flow, leak_alert, anomaly_flags)│
│       ├──► Room 2 data                                        │
│       └──► Room 3 data                                        │
│               │                                               │
│               ▼                                               │
│  Aggregator (every 5 sec)                                    │
│       │                                                       │
│       ├──► Mass Balance Check                                │
│       │       inlet_volume vs. sum(room_volumes)              │
│       │       → balance_flag                                  │
│       │                                                       │
│       ├──► Time-Pattern Check                                │
│       │       current_hour vs. period_baseline                │
│       │       → time_anomaly_flag                             │
│       │                                                       │
│       ├──► Cross-Room Correlation                            │
│       │       IF 2+ rooms have anomaly flags simultaneously  │
│       │       → multi_room_flag (investigate shared pipe)    │
│       │                                                       │
│       └──► Build Firebase payload                             │
│               │                                               │
│               ▼                                               │
│  Firebase RTDB Push                                           │
│       /rooms/{room_id}/anomaly                               │
│       /anomaly/global                                        │
│       /alerts/{alert_id}                                     │
│                                                               │
└──────────────────────────────────────────────────────────────┘
```

---

## 5. Firebase RTDB Data Structure

### 5.1 Per-Room Anomaly Data

```
/tapflow/
├── rooms/
│   ├── 1/
│   │   ├── data/
│   │   │   ├── flow_rate_lpm: 2.34
│   │   │   ├── volume_ml: 456
│   │   │   └── ts: 1703123456789
│   │   ├── anomaly/                    ◄── NEW
│   │   │   ├── spike: false
│   │   │   ├── baseline: false
│   │   │   ├── burst: false
│   │   │   ├── zscore: 0.45
│   │   │   ├── rate_of_change: 0.12
│   │   │   └── ts: 1703123456789
│   │   └── alerts/
│   │       └── {alert_id}/
│   │           ├── type: "anomaly_spike"
│   │           ├── severity: "warning"
│   │           ├── value: 8.5
│   │           ├── threshold: 5.0
│   │           ├── ts: 1703123456789
│   │           └── acknowledged: false
│   ├── 2/
│   │   ├── data/...
│   │   ├── anomaly/...
│   │   └── alerts/...
│   └── 3/
│       ├── data/...
│       ├── anomaly/...
│       └── alerts/...
├── anomaly/                             ◄── NEW (global cross-room)
│   ├── mass_balance/
│   │   ├── inlet_ml: 12500
│   │   ├── rooms_total_ml: 11200
│   │   ├── balance_ml: 1300
│   │   ├── balance_pct: 10.4
│   │   └── ts: 1703123456789
│   ├── time_pattern/
│   │   ├── period: "night"
│   │   ├── usage_ml: 350
│   │   ├── baseline_ml: 50
│   │   ├── deviation_pct: 600
│   │   └── ts: 1703123456789
│   ├── multi_room/
│   │   ├── rooms_active: [1, 2]
│   │   ├── flagged: true
│   │   └── ts: 1703123456789
│   └── trend/
│       ├── slope_lpm: 0.3
│       ├── weekly_increase_pct: 15
│       └── last_check: 1703123456789
├── baselines/                           ◄── NEW (learned patterns)
│   ├── periods/
│   │   ├── night/
│   │   │   ├── avg_ml: 50
│   │   │   └── std_ml: 20
│   │   ├── morning/
│   │   │   ├── avg_ml: 800
│   │   │   └── std_ml: 200
│   │   ├── daytime/
│   │   │   ├── avg_ml: 2000
│   │   │   └── std_ml: 500
│   │   └── evening/
│   │       ├── avg_ml: 1500
│   │       └── std_ml: 400
│   └── daily/
│       ├── 2026-07-14: { room1: 3200, room2: 1800, room3: 2100 }
│       └── ...
└── alerts/
    ├── active/
    │   └── {alert_id}/
    │       ├── type: "anomaly_mass_balance"
    │       ├── severity: "warning"
    │       ├── rooms: [1, 2, 3]
    │       ├── detail: "10.4% unaccounted water"
    │       ├── ts: 1703123456789
    │       └── acknowledged: false
    └── history/
        └── {alert_id}/
            ├── ...
            └── resolved_at: 1703124000000
```

---

## 6. Main ESP32 → Firebase Push Format

### 6.1 Anomaly Data Frame (every 5 sec)

```json
{
  "device_id": "tapflow-main",
  "ts": 1703123456789,
  "type": "anomaly",
  "rooms": [
    {
      "room_id": 1,
      "flow_rate_lpm": 2.34,
      "volume_ml": 456,
      "anomaly": {
        "spike": false,
        "baseline": false,
        "burst": false,
        "zscore": 0.45,
        "rate_of_change": 0.12
      },
      "leak_alert": false
    },
    {
      "room_id": 2,
      "flow_rate_lpm": 0.0,
      "volume_ml": 0,
      "anomaly": {
        "spike": false,
        "baseline": false,
        "burst": false,
        "zscore": 0.0,
        "rate_of_change": 0.0
      },
      "leak_alert": false
    },
    {
      "room_id": 3,
      "flow_rate_lpm": 8.5,
      "volume_ml": 1200,
      "anomaly": {
        "spike": true,
        "baseline": true,
        "burst": false,
        "zscore": 4.2,
        "rate_of_change": 6.8
      },
      "leak_alert": false
    }
  ],
  "global_anomaly": {
    "mass_balance_pct": 10.4,
    "mass_balance_flag": true,
    "time_period": "night",
    "time_anomaly_flag": true,
    "multi_room_flag": false
  }
}
```

### 6.2 Anomaly Alert Frame (on detection)

```json
{
  "device_id": "tapflow-main",
  "ts": 1703123456789,
  "type": "alert",
  "category": "anomaly",
  "severity": "warning",
  "room_id": 3,
  "anomaly_type": "spike",
  "detail": "Flow rate spike: 8.5 L/min (threshold: 5.0 L/min/sec)",
  "value": 8.5,
  "threshold": 5.0,
  "zscore": 4.2,
  "action": "notify"
}
```

### 6.3 Trend Update Frame (daily)

```json
{
  "device_id": "tapflow-main",
  "ts": 1703209800000,
  "type": "trend",
  "room_id": 1,
  "daily_volume_ml": 3200,
  "7day_avg_ml": 2800,
  "7day_std_ml": 400,
  "slope_lpm": 0.3,
  "weekly_increase_pct": 15,
  "flag": true,
  "message": "Room 1 consumption trending upward: +15% week-over-week"
}
```

---

## 7. Alert Severity Levels

| Level | Color | Trigger | Response |
|---|---|---|---|
| **info** | Blue | Z-score 2.0–3.0, minor deviation | Log only |
| **warning** | Yellow | Z-score > 3.0, spike detected, burst, mass balance > 10% | Dashboard notification + log |
| **critical** | Red | Mass balance > 20%, multi-room anomaly, trend > 30% increase | Dashboard alert + push notification + recommend shutoff |
| **emergency** | Red + Flash | Anomaly coincides with leak detection | Emergency shutoff + all alerts |

### Severity Escalation Rules

```
┌─────────────────────────────────────────────────────────────────┐
│  ESCALATION: Warning → Critical                                 │
│  ─────────────────────────────────────────────────────────────  │
│                                                                 │
│  IF anomaly persists for > 5 minutes:                           │
│     severity = warning → critical                               │
│                                                                 │
│  IF anomaly persists for > 15 minutes:                          │
│     severity = critical → emergency                             │
│     → Trigger shutoff recommendation                            │
│                                                                 │
│  IF anomaly coincides with leak_alert:                          │
│     severity = emergency (immediate)                            │
│     → Trigger emergency shutoff                                 │
└─────────────────────────────────────────────────────────────────┘
```

---

## 8. Configuration Thresholds

All thresholds are defined in `config.h` on the ESP32 and can be overridden via Firebase commands from the dashboard.

### Room ESP32 Thresholds

| Parameter | Default | Unit | Config Key |
|---|---|---|---|
| Spike threshold | 5.0 | L/min/sec | `ANOMALY_SPIKE_THRESHOLD` |
| Z-score anomaly | 3.0 | — | `ANOMALY_ZSCORE_ANOMALY` |
| Z-score warning | 2.0 | — | `ANOMALY_ZSCORE_WARNING` |
| Baseline window | 60 | readings | `ANOMALY_BASELINE_WINDOW` |
| Baseline warmup | 12 | readings | `ANOMALY_BASELINE_WARMUP` |
| Burst min rate | 2.0 | L/min | `ANOMALY_BURST_MIN_RATE` |
| Burst max duration | 10 | sec | `ANOMALY_BURST_MAX_DURATION` |
| Burst max volume | 200 | ml | `ANOMALY_BURST_MAX_VOLUME` |

### Main ESP32 Thresholds

| Parameter | Default | Unit | Config Key |
|---|---|---|---|
| Mass balance warning | 10 | % | `ANOMALY_BALANCE_WARNING_PCT` |
| Mass balance anomaly | 20 | % | `ANOMALY_BALANCE_ANOMALY_PCT` |
| Min volume for balance | 5000 | ml | `ANOMALY_BALANCE_MIN_VOLUME` |
| Multi-room threshold | 2 | rooms | `ANOMALY_MULTIROOM_THRESHOLD` |
| Night hours start | 22 | hour | `ANOMALY_NIGHT_START_HOUR` |
| Night hours end | 5 | hour | `ANOMALY_NIGHT_END_HOUR` |

### Dashboard Overrides (Firebase)

Users can adjust thresholds from the web dashboard. Changes are written to Firebase and picked up by the main ESP32 via stream.

```
/tapflow/config/anomaly/
├── spike_threshold: 5.0
├── zscore_anomaly: 3.0
├── balance_warning_pct: 10
├── balance_anomaly_pct: 20
├── night_start_hour: 22
└── night_end_hour: 5
```

---

## 9. Integration with Leak Detection

Anomaly detection and leak detection are **complementary systems** that share data:

```
┌─────────────────────────────────────────────────────────────────┐
│                    DETECTION OVERLAP MATRIX                     │
│  ─────────────────────────────────────────────────────────────  │
│                                                                 │
│  Signal                    │ Leak Detection │ Anomaly Detection │
│  ──────────────────────────┼────────────────┼───────────────────│
│  No RFID + Flow            │ ✅ Rule 1      │ ✅ Z-score spike  │
│  Session ended + Flow      │ ✅ Rule 2      │ ✅ Baseline dev   │
│  Solenoid OFF + Flow       │ ✅ Rule 3      │ — (hardware)      │
│  Continuous flow > 30 min  │ ✅ Rule 4      │ ✅ Trend detect   │
│  Drip 0.1–0.5 L/min > 5m  │ ✅ Rule 5      │ ✅ Burst detect   │
│  Night flow, no session    │ ✅ Rule 6      │ ✅ Time-pattern   │
│  Sudden flow spike         │ —              │ ✅ Rate-of-change │
│  Gradual consumption rise  │ —              │ ✅ Trend detect   │
│  Mass balance mismatch     │ —              │ ✅ Balance check  │
│  Short burst < 10 sec      │ —              │ ✅ Burst detect   │
│  Sensor noise/debris       │ —              │ ✅ Baseline dev   │
│                                                                 │
│  When BOTH flag:  leak_detector overrides anomaly_detector      │
│  Anomaly alone:   warning level only                            │
│  Leak alone:      emergency level                               │
└─────────────────────────────────────────────────────────────────┘
```

### Priority Order

1. **Leak detection rules** run first (critical, immediate shutoff)
2. **Anomaly detection** runs second (warning, logging, trending)
3. If leak detection triggers → anomaly flags are **suppressed** (redundant)
4. If anomaly triggers but no leak → anomaly alert is the **primary signal**

---

## 10. Validation Checklist

Before deploying anomaly detection, verify:

- [ ] **Rate-of-change:** Simulate sudden faucet open → spike detected within 1 reading
- [ ] **Baseline deviation:** Run normal flow for 5 min, then increase by 3x → z-score > 3.0
- [ ] **Burst detection:** Open faucet for 3 sec → burst flagged; open for 30 sec → no burst flag
- [ ] **Mass balance:** Run 10L through inlet, verify room totals sum within 10%
- [ ] **Time-pattern:** Set clock to 2 AM, flow without RFID → night anomaly flagged
- [ ] **Trend detection:** (Cloud) Inject 7 days of increasing data → slope flagged
- [ ] **ESP-NOW payload:** Room ESP32 sends anomaly_flags → main ESP32 receives and decodes
- [ ] **Firebase push:** Main ESP32 writes to `/anomaly/` path → visible in Firebase Console
- [ ] **Dashboard:** Next.js receives anomaly data → shows in real-time feed
- [ ] **Threshold override:** Change threshold from dashboard → ESP32 picks up new value
- [ ] **No false positives:** Normal faucet use for 30 min → zero anomaly alerts
- [ ] **Escalation:** Warning persists 5 min → escalates to critical

---

## Related Guides

| Guide | Relationship |
|---|---|
| [leak-detection-advanced-guide.md](./leak-detection-advanced-guide.md) | Advanced leak rules that complement anomaly detection |
| [module-integration-guide.md](./module-integration-guide.md) | How all ESP32 modules wire together |
| [web-dashboard-alerts-guide.md](./web-dashboard-alerts-guide.md) | Dashboard UI for anomaly visualization |
| [system-architecture.md](./system-architecture.md) | Overall system design |
| [esp32-firmware-complete-guide.md](./esp32-firmware-complete-guide.md) | Base firmware modules |

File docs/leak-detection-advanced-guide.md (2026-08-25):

# Leak Detection Advanced Guide — TapFlow

> **Purpose:** Comprehensive leak detection system — 6 core rules, advanced detection methods, mass balance analysis, and combined anomaly+leak logic.
> **Builds on:** [anomaly-detection-guide.md](./anomaly-detection-guide.md), [block-diagram.md](./block-diagram.md) (6 rules reference)
> **Feeds into:** [module-integration-guide.md](./module-integration-guide.md), [web-dashboard-alerts-guide.md](./web-dashboard-alerts-guide.md)

---

## Table of Contents

1. [Detection Philosophy](#1-detection-philosophy)
2. [6 Core Leak Detection Rules](#2-6-core-leak-detection-rules)
3. [Advanced Detection Methods](#3-advanced-detection-methods)
4. [Mass Balance Leak Detection](#4-mass-balance-leak-detection)
5. [Pulse Pattern Analysis](#5-pulse-pattern-analysis)
6. [Combined Anomaly + Leak Logic](#6-combined-anomaly--leak-logic)
7. [Response Matrix](#7-response-matrix)
8. [False Positive Reduction](#8-false-positive-reduction)
9. [Firebase RTDB Structure](#9-firebase-rtdb-structure)
10. [ESP32 Module: `leak_detector.h`](#10-esp32-module-leak_detectorh)
11. [Configuration Thresholds](#11-configuration-thresholds)
12. [Validation Checklist](#12-validation-checklist)

---

## 1. Detection Philosophy

Leak detection in TapFlow operates on **three principles:**

```
┌─────────────────────────────────────────────────────────────────┐
│  PRINCIPLE 1: REDUNDANCY                                        │
│  ─────────────────────────────────────────────────────────────  │
│  Same event detected from multiple angles:                      │
│    • Room ESP32 (local flow rules)                              │
│    • Main ESP32 (cross-room mass balance)                       │
│    • Firebase Cloud (historical trends)                         │
│  Any 2 of 3 confirming = high confidence alert                 │
└─────────────────────────────────────────────────────────────────┘

┌─────────────────────────────────────────────────────────────────┐
│  PRINCIPLE 2: LAYERED RESPONSE                                  │
│  ─────────────────────────────────────────────────────────────  │
│  Response scales with severity:                                 │
│    • Log only      → suspicious pattern, no action needed       │
│    • Warning       → investigate, notify user                   │
│    • Alert         → recommend shutoff                          │
│    • Emergency     → automatic shutoff + all notifications      │
└─────────────────────────────────────────────────────────────────┘

┌─────────────────────────────────────────────────────────────────┐
│  PRINCIPLE 3: CONTEXT-AWARE                                     │
│  ─────────────────────────────────────────────────────────────  │
│  Same flow reading means different things depending on:         │
│    • RFID session state (authorized vs. unauthorized)           │
│    • Solenoid valve state (commanded ON vs. OFF)                │
│    • Time of day (normal hours vs. night)                       │
│    • Duration (brief use vs. continuous)                        │
│  Detection rules combine ALL context, not just flow rate.       │
└─────────────────────────────────────────────────────────────────┘
```

---

## 2. 6 Core Leak Detection Rules

> These rules run on **every room ESP32** in `local_rules.h`. They are the primary defense and work **offline** (no WiFi needed).

### Rule 1: No RFID + Flow = CRITICAL LEAK

```
┌─────────────────────────────────────────────────────────────────┐
│  RULE 1: NO SESSION + FLOW DETECTED                             │
│  ─────────────────────────────────────────────────────────────  │
│                                                                 │
│  Condition:                                                     │
│    sessionActive == false                                        │
│    AND flowRate > MIN_FLOW_THRESHOLD (0.01 L/min)              │
│    AND持续 for > DEBOUNCE_TIME (3 sec)                         │
│                                                                 │
│  Meaning: No authorized customer in room, but water is flowing. │
│                                                                 │
│  Possible Causes:                                               │
│    • Broken pipe or burst fitting                               │
│    • Stuck solenoid valve (failed open)                         │
│    • Upstream valve failure                                     │
│    • Unauthorized water access                                  │
│                                                                 │
│  Response:                                                      │
│    severity = EMERGENCY                                         │
│    action = emergencyShutoff()                                  │
│    alert = "no_session_flow"                                    │
│    → SSR OFF + Solenoid OFF                                     │
│    → Send alert via ESP-NOW to main ESP32                       │
│    → Log to SPIFFS + Firebase                                   │
│                                                                 │
│  Confidence: HIGH (95%+) — this is almost certainly a leak     │
│  False Positive Rate: < 1% (only if RFID reader malfunction)   │
└─────────────────────────────────────────────────────────────────┘
```

**Pseudocode:**

```cpp
if (!sessionActive && flowRate > MIN_FLOW_THRESHOLD) {
    noFlowDebounce++;
    if (noFlowDebounce > DEBOUNCE_CYCLES) {  // 3 sec at 100ms/cycle
        triggerLeakAlert("no_session_flow", SEVERITY_EMERGENCY);
        emergencyShutoff();
    }
} else {
    noFlowDebounce = 0;
}
```

---

### Rule 2: Session Ended + Flow Continues = SOLENOID STUCK

```
┌─────────────────────────────────────────────────────────────────┐
│  RULE 2: POST-SESSION FLOW                                      │
│  ─────────────────────────────────────────────────────────────  │
│                                                                 │
│  Condition:                                                     │
│    sessionActive == false (session ended)                       │
│    AND solenoidOn == false (solenoid commanded OFF)             │
│    AND flowRate > MIN_FLOW_THRESHOLD (0.01 L/min)              │
│    AND持续 for > DEBOUNCE_TIME (3 sec)                         │
│                                                                 │
│  Meaning: Customer left, solenoid is OFF, but water still flows.│
│                                                                 │
│  Possible Causes:                                               │
│    • Solenoid physically stuck open (mechanical failure)        │
│    • SSR contacts welded shut (relay failure)                   │
│    • Pipe burst downstream of solenoid                          │
│                                                                 │
│  Response:                                                      │
│    severity = EMERGENCY                                         │
│    action = emergencyShutoff()                                  │
│    alert = "post_session_flow"                                  │
│    → SSR OFF + Solenoid OFF (redundant — already OFF)          │
│    → Log hardware failure                                       │
│    → Send alert via ESP-NOW                                     │
│                                                                 │
│  Confidence: VERY HIGH (98%+) — solenoid commanded OFF but     │
│  flow persists = hardware failure                               │
│  False Positive Rate: < 0.5%                                    │
└─────────────────────────────────────────────────────────────────┘
```

---

### Rule 3: Solenoid OFF + Flow = HARDWARE FAILURE

```
┌─────────────────────────────────────────────────────────────────┐
│  RULE 3: SOLENOID OFF + FLOW                                    │
│  ─────────────────────────────────────────────────────────────  │
│                                                                 │
│  Condition:                                                     │
│    solenoidOn == false                                          │
│    AND flowRate > MIN_FLOW_THRESHOLD (0.01 L/min)              │
│    AND持续 for > DEBOUNCE_TIME (3 sec)                         │
│                                                                 │
│  Meaning: Solenoid is commanded closed, but flow sensor reads   │
│  water. Valve is physically stuck open or pipe burst.           │
│                                                                 │
│  Possible Causes:                                               │
│    • Solenoid stuck open (debris, corrosion)                    │
│    • SSR welded contacts (relay keeps passing current)          │
│    • Pipe burst between solenoid and flow sensor                │
│    • Flow sensor error (false positive)                         │
│                                                                 │
│  Response:                                                      │
│    severity = EMERGENCY                                         │
│    action = emergencyShutoff() + retry shutoff (pulse relay)   │
│    alert = "solenoid_stuck_open"                                │
│    → Attempt rapid relay toggle (3x OFF-ON-OFF)                │
│    → If flow persists after retry: hardware alert               │
│    → Send alert via ESP-NOW                                     │
│                                                                 │
│  Confidence: HIGH (90%+) — may need sensor validation          │
│  False Positive Rate: ~2% (sensor noise on startup)            │
└─────────────────────────────────────────────────────────────────┘
```

**Pseudocode:**

```cpp
if (!solenoidOn && flowRate > MIN_FLOW_THRESHOLD) {
    stuckDebounce++;
    if (stuckDebounce > DEBOUNCE_CYCLES) {
        // Attempt relay reset (toggle 3x)
        for (int i = 0; i < 3; i++) {
            digitalWrite(PIN_RELAY, HIGH); delay(200);
            digitalWrite(PIN_RELAY, LOW);  delay(200);
        }
        // Check if flow stopped
        delay(1000);
        if (flowRate > MIN_FLOW_THRESHOLD) {
            triggerLeakAlert("solenoid_stuck_open", SEVERITY_EMERGENCY);
            // Hardware failure — relay toggle didn't help
        }
    }
} else {
    stuckDebounce = 0;
}
```

---

### Rule 4: Continuous Flow > 30 Min = STUCK VALVE

```
┌─────────────────────────────────────────────────────────────────┐
│  RULE 4: CONTINUOUS FLOW                                        │
│  ─────────────────────────────────────────────────────────────  │
│                                                                 │
│  Condition:                                                     │
│    flowRate > MIN_FLOW_THRESHOLD (0.01 L/min)                  │
│    AND持续时间 > CONTINUOUS_FLOW_MIN (30 minutes)              │
│                                                                 │
│  Meaning: Water has been flowing non-stop for 30+ minutes.      │
│  Even with active session, this is abnormal.                    │
│                                                                 │
│  Possible Causes:                                               │
│    • Stuck valve (solenoid or faucet)                           │
│    • Running toilet (flapper not sealing)                       │
│    • Forgotten faucet left open                                 │
│    • Slow leak from loose fitting                               │
│                                                                 │
│  Response:                                                      │
│    severity = ALERT                                             │
│    action = emergencyShutoff() if no session,                   │
│             warnUser() if session active                        │
│    alert = "continuous_flow"                                    │
│    → If session active: warn via LED + log                      │
│    → If no session: emergency shutoff                           │
│    → Send alert via ESP-NOW                                     │
│                                                                 │
│  Confidence: MEDIUM (80%) — some legitimate uses last long      │
│  (filling large container, garden hose)                         │
│  False Positive Rate: ~5% (legitimate long-use scenarios)       │
└─────────────────────────────────────────────────────────────────┘
```

**Pseudocode:**

```cpp
if (flowRate > MIN_FLOW_THRESHOLD) {
    continuousFlowTime += SEND_INTERVAL_MS / 1000;  // accumulate seconds
    if (continuousFlowTime > CONTINUOUS_FLOW_MIN * 60) {
        if (!sessionActive) {
            triggerLeakAlert("continuous_flow", SEVERITY_ALERT);
            emergencyShutoff();
        } else {
            triggerLeakAlert("continuous_flow", SEVERITY_WARNING);
            // Warn user — don't shutoff during active session
        }
    }
} else {
    continuousFlowTime = 0;  // reset when flow stops
}
```

---

### Rule 5: Drip Leak (0.1–0.5 L/min > 5 Min)

```
┌─────────────────────────────────────────────────────────────────┐
│  RULE 5: DRIP LEAK                                              │
│  ─────────────────────────────────────────────────────────────  │
│                                                                 │
│  Condition:                                                     │
│    flowRate > DRIP_MIN_RATE (0.1 L/min)                        │
│    AND flowRate < DRIP_MAX_RATE (0.5 L/min)                    │
│    AND持续时间 > DRIP_MIN_TIME (5 minutes)                     │
│    AND sessionActive == false (no authorized user)              │
│                                                                 │
│  Meaning: Slow, steady trickle for extended period with no      │
│  authorized user. Classic drip leak signature.                  │
│                                                                 │
│  Possible Causes:                                               │
│    • Dripping faucet (worn washer/O-ring)                       │
│    • Loose pipe fitting                                         │
│    • Slow leak from check valve                                 │
│    • Toilet flapper leak                                        │
│                                                                 │
│  Response:                                                      │
│    severity = WARNING                                           │
│    action = log + notify                                        │
│    alert = "drip_leak"                                          │
│    → No emergency shutoff (drip is slow, not critical)          │
│    → Log to Firebase for trend analysis                         │
│    → Dashboard notification                                     │
│    → Recommend maintenance                                      │
│                                                                 │
│  Confidence: MEDIUM (75%) — drip rate can overlap with normal   │
│  low-flow usage (filling a glass)                               │
│  False Positive Rate: ~8% (normal low-flow use < 5 min)        │
└─────────────────────────────────────────────────────────────────┘
```

**Pseudocode:**

```cpp
if (flowRate > DRIP_MIN_RATE && flowRate < DRIP_MAX_RATE && !sessionActive) {
    dripTime += SEND_INTERVAL_MS / 1000;
    if (dripTime > DRIP_MIN_TIME * 60) {
        triggerLeakAlert("drip_leak", SEVERITY_WARNING);
        // Don't shutoff — drip is slow, recommend maintenance
    }
} else {
    dripTime = 0;
}
```

---

### Rule 6: Night Flow (22:00–05:00) = SUSPICIOUS

```
┌─────────────────────────────────────────────────────────────────┐
│  RULE 6: NIGHT FLOW                                             │
│  ─────────────────────────────────────────────────────────────  │
│                                                                 │
│  Condition:                                                     │
│    current_hour >= NIGHT_START_HOUR (22)                        │
│    OR current_hour < NIGHT_END_HOUR (5)                         │
│    AND flowRate > MIN_FLOW_THRESHOLD (0.01 L/min)              │
│    AND sessionActive == false (no authorized user)              │
│                                                                 │
│  Meaning: Water flowing during sleeping hours with no           │
│  authorized user. Possible leak, unauthorized use, or           │
│  pipe burst.                                                    │
│                                                                 │
│  Possible Causes:                                               │
│    • Pipe burst at night (undetected)                           │
│    • Unauthorized water access                                  │
│    • Toilet running (flapper leak)                              │
│    • Irrigation system malfunction                              │
│                                                                 │
│  Response:                                                      │
│    severity = ALERT                                             │
│    action = emergencyShutoff()                                  │
│    alert = "night_flow"                                         │
│    → Emergency shutoff (conservative — night = unattended)      │
│    → Send alert via ESP-NOW                                     │
│    → Log to Firebase                                            │
│    → Dashboard push notification                                │
│                                                                 │
│  Confidence: HIGH (90%) — night flow with no session is         │
│  almost always a problem                                        │
│  False Positive Rate: ~3% (late-night legitimate use)           │
└─────────────────────────────────────────────────────────────────┘
```

---

## 3. Advanced Detection Methods

Beyond the 6 core rules, these methods catch leaks that the basic rules miss.

### 3.1 Slow Accumulation Leak

A leak too small to trigger Rule 5 (drip) but detectable over hours.

```
┌─────────────────────────────────────────────────────────────────┐
│  METHOD: Slow Accumulation                                      │
│  ─────────────────────────────────────────────────────────────  │
│                                                                 │
│  Logic:                                                         │
│    Track cumulative volume when NO session is active            │
│    IF unauthorized_volume > SLOW_LEAK_THRESHOLD (500 ml/hr)    │
│       → FLAG: slow accumulation leak                            │
│                                                                 │
│  Why it works:                                                  │
│    Normal rooms have 0 ml unauthorized volume.                  │
│    Any sustained accumulation = hidden leak.                    │
│                                                                 │
│  Runs on: Main ESP32 (aggregates across rooms)                 │
│  Window: 1 hour                                                 │
│  Threshold: 500 ml/hr (configurable)                           │
└─────────────────────────────────────────────────────────────────┘
```

### 3.2 Flow After Shutoff

Detects water flowing after the main ESP32 has commanded solenoid shutoff.

```
┌─────────────────────────────────────────────────────────────────┐
│  METHOD: Post-Shutoff Flow                                      │
│  ─────────────────────────────────────────────────────────────  │
│                                                                 │
│  Logic:                                                         │
│    Main ESP32 commands solenoid OFF                             │
│    Waits 5 seconds for solenoid to close                        │
│    Reads calibrated flow sensor                                 │
│    IF flow > 0.01 L/min after shutoff:                          │
│       → FLAG: solenoid failure or downstream burst              │
│       → Attempt shutoff on SECOND solenoid (redundancy)         │
│       → If still flowing: CRITICAL hardware alert               │
│                                                                 │
│  Why it works:                                                  │
│    Dual-solenoid design allows verification.                    │
│    If both solenoids OFF but flow persists = pipe burst.        │
│                                                                 │
│  Runs on: Main ESP32 only (has both solenoids)                 │
│  Delay: 5 sec after shutoff command                             │
└─────────────────────────────────────────────────────────────────┘
```

### 3.3 Sensor Disagreement

Detects when room sensors and main sensor disagree beyond calibration error.

```
┌─────────────────────────────────────────────────────────────────┐
│  METHOD: Sensor Disagreement                                    │
│  ─────────────────────────────────────────────────────────────  │
│                                                                 │
│  Logic:                                                         │
│    main_volume = calibrated sensor reading                      │
│    room_sum = sum of all room uncalibrated readings             │
│    expected_ratio = main_volume / room_sum                     │
│                                                                 │
│    IF expected_ratio > 1.5 OR expected_ratio < 0.5:            │
│       → FLAG: sensor disagreement                               │
│       → Possible: sensor failure, debris, air bubble            │
│       → Action: log warning, recommend calibration check        │
│                                                                 │
│  Why it works:                                                  │
│    Room sensors are uncalibrated (±10-15%), but a 50%+          │
│    discrepancy means something is wrong.                        │
│                                                                 │
│  Runs on: Main ESP32                                            │
│  Min volume: 5L (for meaningful ratio)                          │
└─────────────────────────────────────────────────────────────────┘
```

### 3.4 Intermittent Leak Detection

Catches leaks that come and go (e.g., pressure-dependent leaks).

```
┌─────────────────────────────────────────────────────────────────┐
│  METHOD: Intermittent Leak                                      │
│  ─────────────────────────────────────────────────────────────  │
│                                                                 │
│  Logic:                                                         │
│    Track leak alert count per room in rolling 1-hour window     │
│    IF leak_alert_count > INTERMITTENT_THRESHOLD (3):            │
│       → FLAG: intermittent leak                                 │
│       → Same room keeps triggering briefly, then stops          │
│       → Action: escalate to WARNING (investigate)               │
│                                                                 │
│  Why it works:                                                  │
│    Intermittent leaks trigger Rule 1 or Rule 2 briefly,         │
│    then stop (pressure equalizes, valve reseats).               │
│    Multiple brief triggers in short window = real problem.      │
│                                                                 │
│  Runs on: Main ESP32 (tracks across room reports)              │
│  Window: 1 hour                                                 │
│  Threshold: 3 triggers per hour                                 │
└─────────────────────────────────────────────────────────────────┘
```

---

## 4. Mass Balance Leak Detection

> Cross-references the **calibrated inlet sensor** (main ESP32) against **uncalibrated room sensors** to detect hidden leaks in pipe runs.

### 4.1 How Mass Balance Works

```
                    ┌──────────────────────┐
                    │   Calibrated Sensor  │
                    │   (Main ESP32)       │
                    │   Volume = 12,500 ml │
                    └──────────┬───────────┘
                               │
                    ┌──────────▼───────────┐
                    │    T-Connector Split  │
                    └──┬───────┬────────┬──┘
                       │       │        │
              ┌────────▼──┐ ┌──▼──────┐ ┌▼────────┐
              │ Room 1    │ │ Room 2  │ │ Room 3  │
              │ 4,500 ml  │ │ 3,200ml │ │ 3,500ml │
              └───────────┘ └─────────┘ └─────────┘

              Room Sum = 4,500 + 3,200 + 3,500 = 11,200 ml
              Balance  = 12,500 - 11,200 = 1,300 ml (10.4%)
```

### 4.2 Balance Thresholds

| Balance % | Status | Action |
|---|---|---|
| < 5% | ✅ Normal | Within calibration error margin |
| 5–10% | ℹ️ Info | Log for trend analysis |
| 10–20% | ⚠️ Warning | Investigate pipe connections, check for drips |
| > 20% | 🔴 Anomaly | Hidden leak between main and rooms — urgent investigation |

### 4.3 Balance Calculation Rules

```
┌─────────────────────────────────────────────────────────────────┐
│  MASS BALANCE CALCULATION                                       │
│  ─────────────────────────────────────────────────────────────  │
│                                                                 │
│  Inputs:                                                        │
│    inlet_ml    — calibrated sensor total (main ESP32)           │
│    room_ml[]   — uncalibrated sensor totals (room ESP32s)       │
│                                                                 │
│  Computation:                                                   │
│    expected = room_ml[0] + room_ml[1] + room_ml[2]             │
│    balance_ml = inlet_ml - expected                             │
│    balance_pct = (balance_ml / inlet_ml) × 100                 │
│                                                                 │
│  Guard conditions:                                              │
│    • Skip if inlet_ml < 5000 ml (too small for meaningful %)   │
│    • Skip if any room sensor read error (pulses = 0 but flow > 0)│
│    • Average over 5-minute window (reduce noise)                │
│                                                                 │
│  Output:                                                        │
│    balance_flag = (|balance_pct| > ANOMALY_BALANCE_ANOMALY_PCT)│
│    balance_severity = based on threshold table above            │
└─────────────────────────────────────────────────────────────────┘
```

### 4.4 Balance Over Time

Track balance trends to distinguish **calibration drift** from **real leaks:**

```
Day 1: balance = +8%   (calibration error, stable)
Day 2: balance = +9%   (stable)
Day 3: balance = +11%  (starting to increase)
Day 4: balance = +14%  (increasing — possible leak)
Day 5: balance = +18%  (likely leak — investigate)
Day 6: balance = +22%  (confirmed leak — urgent)
```

If balance **increases over days**, it's a growing leak. If balance is **stable**, it's calibration error.

---

## 5. Pulse Pattern Analysis

Analyzes the raw pulse stream from flow sensors to detect **non-flow anomalies.**

### 5.1 Sensor Noise / Debris

```
┌─────────────────────────────────────────────────────────────────┐
│  PATTERN: Erratic Pulses                                        │
│  ─────────────────────────────────────────────────────────────  │
│                                                                 │
│  Normal pulse pattern:                                          │
│    ─┐ ┌─┐ ┌─┐ ┌─┐ ┌─┐ ┌─┐ ┌─  (regular, ~10ms apart)        │
│     └─┘ └─┘ └─┘ └─┘ └─┘ └─┘                                  │
│                                                                 │
│  Noisy pulse pattern:                                           │
│    ─┐ ┌┐┌─┐  ┌─┐┌┐ ┌┐ ┌─┐ ┌  (irregular, varying intervals)  │
│     └─┘└┘ └──┘ └┘└─┘└─┘ └─┘                                  │
│                                                                 │
│  Detection:                                                     │
│    • Compute variance of inter-pulse intervals                 │
│    • Normal: variance < 5 ms²                                   │
│    • Noisy:  variance > 20 ms²                                  │
│    • IF noisy AND flow > 0:                                     │
│       → FLAG: sensor may have debris                            │
│       → Action: log warning, recommend sensor cleaning          │
│                                                                 │
│  Runs on: Room ESP32 (closest to sensor)                       │
└─────────────────────────────────────────────────────────────────┘
```

### 5.2 No-Flow Pulse Detection

Detects pulses when no water should be flowing (sensor malfunction or air bubbles).

```
┌─────────────────────────────────────────────────────────────────┐
│  PATTERN: Ghost Pulses                                          │
│  ─────────────────────────────────────────────────────────────  │
│                                                                 │
│  Condition:                                                     │
│    pulses > 0 AND flowRate == 0 (after PPL calculation)        │
│    AND sessionActive == false                                   │
│                                                                 │
│  Meaning: Sensor is generating pulses but calculated flow       │
│  is zero. Could be:                                             │
│    • Air bubbles in sensor (turbulence)                         │
│    • Sensor Hall effect noise                                   │
│    • EMI interference                                           │
│                                                                 │
│  Detection:                                                     │
│    IF ghost_pulse_count > 10 per 5-sec interval:               │
│       → FLAG: sensor calibration issue                          │
│       → Action: log, recommend recalibration                    │
│                                                                 │
│  Runs on: Room ESP32                                            │
└─────────────────────────────────────────────────────────────────┘
```

### 5.3 Pulse Saturation

Detects when the sensor is maxed out (flow exceeds sensor range).

```
┌─────────────────────────────────────────────────────────────────┐
│  PATTERN: Pulse Saturation                                      │
│  ─────────────────────────────────────────────────────────────  │
│                                                                 │
│  YF-S201 max flow: ~30 L/min                                   │
│  At 450 PPL: ~22,500 pulses/min = 375 pulses/sec              │
│                                                                 │
│  Condition:                                                     │
│    pulse_count_this_interval > SATURATION_THRESHOLD             │
│    (e.g., > 3000 pulses in 5 sec = 10 L/min sustained)        │
│                                                                 │
│  Meaning: Flow rate exceeds normal household range.             │
│  Could be main pipe burst or sensor error.                      │
│                                                                 │
│  Detection:                                                     │
│    IF pulses > SATURATION_THRESHOLD:                            │
│       → FLAG: high flow anomaly                                 │
│       → Action: log alert, check for major leak                 │
│                                                                 │
│  Runs on: Room ESP32 + Main ESP32                              │
└─────────────────────────────────────────────────────────────────┘
```

---

## 6. Combined Anomaly + Leak Logic

When anomaly detection and leak detection both flag the same event, the system uses a **combined decision matrix.**

### 6.1 Decision Matrix

| Leak Rule | Anomaly Signal | Combined Severity | Action |
|---|---|---|---|
| Rule 1 (no session + flow) | Spike detected | **EMERGENCY** | Immediate shutoff |
| Rule 1 (no session + flow) | Baseline deviation | **EMERGENCY** | Immediate shutoff |
| Rule 1 (no session + flow) | No anomaly signal | **EMERGENCY** | Immediate shutoff (leak alone is enough) |
| Rule 4 (continuous flow) | Trend increasing | **CRITICAL** | Shutoff + investigate |
| Rule 4 (continuous flow) | No trend | **WARNING** | Warn user, log |
| Rule 5 (drip leak) | Burst detected | **WARNING** | Log + recommend maintenance |
| Rule 5 (drip leak) | No burst | **INFO** | Log only |
| Rule 6 (night flow) | Time-pattern anomaly | **EMERGENCY** | Immediate shutoff |
| No leak rule triggered | Spike detected | **WARNING** | Log + notify |
| No leak rule triggered | Z-score > 3.0 | **WARNING** | Log + notify |
| No leak rule triggered | Mass balance > 20% | **CRITICAL** | Investigate pipes |
| No leak rule triggered | Trend > 30% increase | **WARNING** | Recommend audit |

### 6.2 Priority Override Rules

```
┌─────────────────────────────────────────────────────────────────┐
│  OVERRIDE RULES                                                 │
│  ─────────────────────────────────────────────────────────────  │
│                                                                 │
│  1. LEAK RULES ALWAYS WIN                                       │
│     If any leak rule triggers → anomaly flags are suppressed    │
│     (leak detection is more specific, anomaly is redundant)     │
│                                                                 │
│  2. HIGHEST SEVERITY PREVAILS                                   │
│     If both systems flag: max(leak_severity, anomaly_severity)  │
│                                                                 │
│  3. COMBINED CONFIDENCE BOOST                                   │
│     If BOTH systems flag the same room:                         │
│        confidence = leak_confidence × 1.5 (capped at 100%)     │
│        → Dashboard shows "HIGH CONFIDENCE" badge                │
│                                                                 │
│  4. DEDUPLICATION                                               │
│     If leak alert + anomaly alert fire within 10 sec of each   │
│     other for the same room:                                    │
│        → Merge into single alert                                │
│        → Record both sources in alert detail                    │
└─────────────────────────────────────────────────────────────────┘
```

### 6.3 Combined Detection Flow

```
┌─────────────────────────────────────────────────────────────────┐
│                    COMBINED DETECTION FLOW                      │
│  ─────────────────────────────────────────────────────────────  │
│                                                                 │
│  Room ESP32 (per cycle):                                        │
│  ┌───────────────────────────────────────────────────────────┐  │
│  │  1. Read flow sensor                                      │  │
│  │  2. Run Leak Rules 1-6 → leak_flags                      │  │
│  │  3. Run Anomaly Detection → anomaly_flags                 │  │
│  │  4. Merge: combined_flags = leak_flags OR anomaly_flags   │  │
│  │  5. If leak_flags: suppress anomaly (redundant)           │  │
│  │  6. Send combined_flags via ESP-NOW                       │  │
│  └───────────────────────────────────────────────────────────┘  │
│                              │                                  │
│                              ▼                                  │
│  Main ESP32 (per 5 sec):                                       │
│  ┌───────────────────────────────────────────────────────────┐  │
│  │  1. Receive room data + combined_flags                    │  │
│  │  2. Run Mass Balance check → balance_flag                 │  │
│  │  3. Run Time-Pattern check → time_flag                    │  │
│  │  4. Run Post-Shutoff verification → shutoff_flag          │  │
│  │  5. Cross-room correlation → multi_room_flag              │  │
│  │  6. Combine all flags → global_severity                   │  │
│  │  7. Execute response matrix (shutoff/warn/log)            │  │
│  │  8. Push to Firebase RTDB                                 │  │
│  └───────────────────────────────────────────────────────────┘  │
│                              │                                  │
│                              ▼                                  │
│  Firebase Cloud:                                                │
│  ┌───────────────────────────────────────────────────────────┐  │
│  │  1. Store alert in /alerts/active/                        │  │
│  │  2. Store in /alerts/history/ for audit trail             │  │
│  │  3. Update /rooms/{id}/anomaly/ with latest flags         │  │
│  │  4. Trigger Cloud Function for push notification          │  │
│  │  5. Update daily baselines for trend analysis             │  │
│  └───────────────────────────────────────────────────────────┘  │
│                              │                                  │
│                              ▼                                  │
│  Next.js Dashboard:                                            │
│  ┌───────────────────────────────────────────────────────────┐  │
│  │  1. onValue listener on /alerts/active/                   │  │
│  │  2. Render real-time alert cards                          │  │
│  │  3. Show severity badge (info/warning/critical/emergency) │  │
│  │  4. Allow acknowledge/dismiss                             │  │
│  │  5. Show trend charts with anomaly markers                │  │
│  └───────────────────────────────────────────────────────────┘  │
│                                                                 │
└─────────────────────────────────────────────────────────────────┘
```

---

## 7. Response Matrix

### 7.1 Automatic Responses

| Severity | Solenoid | SSR | LED | Firebase Alert | Dashboard | Push Notification |
|---|---|-----|-----|---|---|---|
| **INFO** | No change | No change | Green | Log only | Badge | No |
| **WARNING** | No change | No change | Yellow blink | ✅ | Card + badge | No |
| **ALERT** | OFF | OFF | Yellow solid | ✅ | Card + popup | ✅ |
| **CRITICAL** | OFF | OFF | Red solid | ✅ | Card + popup + banner | ✅ |
| **EMERGENCY** | OFF | OFF | Red flash | ✅ + escalation | Full-screen alert | ✅ + SMS (if configured) |

### 7.2 Escalation Timeline

```
T+0 sec:   Anomaly/leak detected
T+0 sec:   Room ESP32 sends alert via ESP-NOW
T+0-5 sec: Main ESP32 receives, validates, pushes to Firebase
T+5 sec:   Dashboard shows alert card
T+30 sec:  If warning persists → escalate to alert
T+5 min:   If alert persists → escalate to critical
T+15 min:  If critical persists → escalate to emergency
T+15 min:  Emergency → recommend manual intervention
```

### 7.3 Recovery Flow

```
┌─────────────────────────────────────────────────────────────────┐
│  RECOVERY: After Leak/Anomaly Resolved                          │
│  ─────────────────────────────────────────────────────────────  │
│                                                                 │
│  1. Flow stops (leak fixed, valve replaced, etc.)               │
│  2. Room ESP32 detects flow == 0 for > 30 sec                  │
│  3. Clears leak/anomaly flags                                   │
│  4. Sends "resolved" status via ESP-NOW                         │
│  5. Main ESP32 updates Firebase:                                │
│     /alerts/active/{id}/resolved_at = timestamp                 │
│     Moves alert to /alerts/history/                             │
│  6. Dashboard:                                                  │
│     Alert card moves from "Active" to "History" tab             │
│     Green "Resolved" badge shown                                │
│  7. User can manually re-enable solenoid from dashboard        │
│     (solenoid stays OFF until explicit re-enable)               │
│                                                                 │
└─────────────────────────────────────────────────────────────────┘
```

---

## 8. False Positive Reduction

### 8.1 Debouncing

All leak rules require **sustained conditions** before triggering:

| Rule | Debounce Time | Rationale |
|---|---|---|
| Rule 1 (no session + flow) | 3 sec | Prevents trigger on sensor noise |
| Rule 2 (post-session flow) | 3 sec | Solenoid needs time to close |
| Rule 3 (solenoid OFF + flow) | 3 sec + retry | May be sensor startup noise |
| Rule 4 (continuous flow) | 30 min | Long window avoids legitimate uses |
| Rule 5 (drip leak) | 5 min | Distinguish drip from normal low-flow |
| Rule 6 (night flow) | 3 sec | Night = conservative, short debounce OK |

### 8.2 Context Requirements

Each rule requires **specific context** to reduce false positives:

```
┌─────────────────────────────────────────────────────────────────┐
│  CONTEXT REQUIREMENTS PER RULE                                  │
│  ─────────────────────────────────────────────────────────────  │
│                                                                 │
│  Rule 1: !sessionActive AND flowRate > threshold                │
│          (RFID state is critical context)                       │
│                                                                 │
│  Rule 2: !sessionActive AND !solenoidOn AND flowRate > threshold│
│          (Both RFID AND solenoid state required)                │
│                                                                 │
│  Rule 3: !solenoidOn AND flowRate > threshold                   │
│          (Solenoid state is critical)                           │
│                                                                 │
│  Rule 4: flowRate > threshold AND duration > 30 min             │
│          (Time is the differentiator)                            │
│                                                                 │
│  Rule 5: flowRate in [0.1, 0.5] AND duration > 5 min           │
│          AND !sessionActive                                     │
│          (Rate range + time + RFID state)                       │
│                                                                 │
│  Rule 6: isNightTime() AND flowRate > threshold                 │
│          AND !sessionActive                                     │
│          (Time + RFID state)                                    │
│                                                                 │
└─────────────────────────────────────────────────────────────────┘
```

### 8.3 Learning from History

The system learns normal patterns to reduce future false positives:

- **Daily baselines** per room per time period (stored in Firebase)
- **Per-room calibration** factors (updated via bucket test)
- **User feedback** — "this was not a leak" button on dashboard adjusts thresholds

---

## 9. Firebase RTDB Structure

### 9.1 Active Alerts

```
/tapflow/alerts/active/{alert_id}
├── type: "leak" | "anomaly" | "combined"
├── rule: "no_session_flow" | "solenoid_stuck_open" | "continuous_flow" | ...
├── severity: "info" | "warning" | "alert" | "critical" | "emergency"
├── room_id: 1
├── device_id: "tapflow-room1"
├── ts: 1703123456789
├── detail: "Flow detected with no active RFID session"
├── flow_rate_lpm: 2.34
├── threshold: 0.01
├── anomaly_context:
│   ├── zscore: 4.2
│   ├── spike: true
│   └── burst: false
├── acknowledged: false
├── acknowledged_by: null
├── resolved: false
└── resolved_at: null
```

### 9.2 Alert History

```
/tapflow/alerts/history/{alert_id}
├── (same fields as active)
├── resolved_at: 1703124000000
├── duration_sec: 544
├── response_time_sec: 5
├── auto_shutoff: true
└── user_action: "replaced solenoid valve"
```

### 9.3 Leak Event Log

```
/tapflow/events/leaks/{event_id}
├── room_id: 2
├── rule: "solenoid_stuck_open"
├── ts_start: 1703123456789
├── ts_end: 1703124000000
├── duration_sec: 544
├── volume_lost_ml: 12500
├── severity: "emergency"
├── auto_shutoff: true
├── shutoff_time_sec: 5
└── resolution: "hardware_replacement"
```

---

## 10. ESP32 Module: `leak_detector.h`

### 10.1 Room ESP32 Leak Detector

**Responsibilities:**
- Run 6 core leak detection rules
- Manage debounce timers per rule
- Control emergency shutoff
- Export leak flags via ESP-NOW

**Interface:**

```cpp
class LeakDetector {
public:
    void begin();                          // Initialize thresholds from config.h
    void checkAll(                         // Run all rules every cycle
        float flowRate,
        bool sessionActive,
        bool solenoidOn,
        float continuousFlowTime,
        float dripTime,
        bool isNightTime
    );
    bool isLeakActive();                   // Any leak rule currently triggered
    uint8_t getLeakFlags();                // Bitmask of active rules
    const char* getLeakType();             // Highest severity leak type
    void emergencyShutoff();               // SSR OFF + Solenoid OFF
    void acknowledge();                    // User acknowledged alert
};
```

**Leak flag bitmask:**

| Bit | Rule | Name |
|-----|---|---|
| 0 | Rule 1 | `no_session_flow` |
| 1 | Rule 2 | `post_session_flow` |
| 2 | Rule 3 | `solenoid_stuck_open` |
| 3 | Rule 4 | `continuous_flow` |
| 4 | Rule 5 | `drip_leak` |
| 5 | Rule 6 | `night_flow` |

### 10.2 Main ESP32 Leak Detector

**Responsibilities:**
- Aggregate room leak flags
- Mass balance check
- Post-shutoff verification (dual solenoid)
- Intermittent leak detection
- Push to Firebase

**Interface:**

```cpp
class MainLeakDetector {
public:
    void begin();
    void checkAll(                         // Run every 5 sec
        RoomData rooms[],                  // ESP-NOW data from 3 rooms
        float inletVolume,                 // Calibrated sensor reading
        bool solenoid1On,
        bool solenoid2On
    );
    bool isGlobalLeakActive();
    int getGlobalSeverity();               // Max severity across all rooms
    void pushToFirebase(FirebaseData &fb); // Write alerts + data to RTDB
    void verifyShutoff();                  // Check flow after solenoid OFF
};
```

---

## 11. Configuration Thresholds

### Room ESP32

| Parameter | Default | Unit | Config Key |
|---|---|---|---|
| Min flow threshold | 0.01 | L/min | `MIN_FLOW_THRESHOLD` |
| Debounce cycles | 30 | cycles (×100ms) | `LEAK_DEBOUNCE_CYCLES` |
| Continuous flow min | 30 | minutes | `CONTINUOUS_FLOW_MIN` |
| Drip min rate | 0.1 | L/min | `DRIP_MIN_RATE` |
| Drip max rate | 0.5 | L/min | `DRIP_MAX_RATE` |
| Drip min time | 5 | minutes | `DRIP_MIN_TIME` |
| Night start hour | 22 | hour | `NIGHT_START_HOUR` |
| Night end hour | 5 | hour | `NIGHT_END_HOUR` |
| Solenoid off delay | 5 | seconds | `SOLENOID_OFF_DELAY_MS` |
| Session timeout | 10 | minutes | `SESSION_TIMEOUT_MS` |

### Main ESP32

| Parameter | Default | Unit | Config Key |
|---|---|---|---|
| Balance warning % | 10 | % | `BALANCE_WARNING_PCT` |
| Balance anomaly % | 20 | % | `BALANCE_ANOMALY_PCT` |
| Min volume for balance | 5000 | ml | `BALANCE_MIN_VOLUME` |
| Slow leak threshold | 500 | ml/hr | `SLOW_LEAK_THRESHOLD` |
| Intermittent threshold | 3 | triggers/hr | `INTERMITTENT_THRESHOLD` |
| Post-shutoff delay | 5 | seconds | `POST_SHUTOFF_DELAY` |
| Sensor disagreement | 50 | % | `SENSOR_DISAGREEMENT_PCT` |
| Saturation threshold | 3000 | pulses/5sec | `SATURATION_THRESHOLD` |

---

## 12. Validation Checklist

- [ ] **Rule 1:** Simulate RFID removed while faucet running → emergency shutoff within 3 sec
- [ ] **Rule 2:** End RFID session while water flows → emergency shutoff within 3 sec
- [ ] **Rule 3:** Command solenoid OFF while flow persists → relay retry + alert
- [ ] **Rule 4:** Run water for 31 min without stopping → continuous flow alert
- [ ] **Rule 5:** Simulate drip (0.2 L/min) for 6 min → drip leak warning
- [ ] **Rule 6:** Set clock to 2 AM, flow without RFID → night flow alert
- [ ] **Mass balance:** Run 10L through inlet, verify rooms sum within 10%
- [ ] **Mass balance:** Block one room pipe → balance > 20% flagged
- [ ] **Post-shutoff:** Command solenoid OFF, verify flow stops within 5 sec
- [ ] **Intermittent:** Trigger Rule 1 three times in 1 hour → intermittent flag
- [ ] **Debounce:** Brief flow burst (< 3 sec) → no leak alert (debounce filters)
- [ ] **False positive:** Normal faucet use for 30 min → zero leak alerts
- [ ] **Combined:** Leak + anomaly both flag → merged alert, highest severity
- [ ] **Recovery:** Fix leak, flow stops → alert resolved, solenoid stays OFF until re-enable
- [ ] **Firebase:** Alert appears in `/alerts/active/` within 5 sec of detection
- [ ] **Dashboard:** Alert card shows within 5 sec of Firebase write

---

## Related Guides

| Guide | Relationship |
|---|---|
| [anomaly-detection-guide.md](./anomaly-detection-guide.md) | Anomaly algorithms that complement leak rules |
| [module-integration-guide.md](./module-integration-guide.md) | How ESP32 modules wire together |
| [web-dashboard-alerts-guide.md](./web-dashboard-alerts-guide.md) | Dashboard UI for leak visualization |
| [block-diagram.md](./block-diagram.md) | 6 rules reference diagram |
| [system-architecture.md](./system-architecture.md) | Overall system design |

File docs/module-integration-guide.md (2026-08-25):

# Module Integration Guide — TapFlow

> **Purpose:** How all ESP32 modules wire together to form the complete anomaly detection + leak detection system. Covers module responsibilities, data flow, ESP-NOW protocol, and Firebase integration.
> **Builds on:** [anomaly-detection-guide.md](./anomaly-detection-guide.md), [leak-detection-advanced-guide.md](./leak-detection-advanced-guide.md)
> **Feeds into:** [web-dashboard-alerts-guide.md](./web-dashboard-alerts-guide.md)

---

## Table of Contents

1. [Module Overview](#1-module-overview)
2. [Room ESP32 Module Architecture](#2-room-esp32-module-architecture)
3. [Main ESP32 Module Architecture](#3-main-esp32-module-architecture)
4. [Module Responsibilities Matrix](#4-module-responsibilities-matrix)
5. [Data Flow: Sensor → Detection → Alert → Firebase](#5-data-flow-sensor--detection--alert--firebase)
6. [ESP-NOW Protocol (Room → Main)](#6-espnow-protocol-room--main)
7. [Firebase RTDB Integration](#7-firebase-rtdb-integration)
8. [Module Initialization Order](#8-module-initialization-order)
9. [Main Loop Execution Order](#9-main-loop-execution-order)
10. [Error Handling & Fallbacks](#10-error-handling--fallbacks)
11. [Configuration Management](#11-configuration-management)
12. [Validation Checklist](#12-validation-checklist)

---

## 1. Module Overview

### Room ESP32 Modules (×3)

```
┌─────────────────────────────────────────────────────────────────┐
│  ROOM ESP32 MODULE STACK                                        │
│  ─────────────────────────────────────────────────────────────  │
│                                                                 │
│  ┌───────────────────────────────────────────────────────────┐  │
│  │  water-meter.ino          Main sketch (setup + loop)      │  │
│  └───────────────────────┬───────────────────────────────────┘  │
│                          │                                      │
│  ┌───────────────────────▼───────────────────────────────────┐  │
│  │  config.h              All parameters (pins, thresholds)  │  │
│  └───────────────────────┬───────────────────────────────────┘  │
│                          │                                      │
│  ┌───────────┬───────────┼───────────┬───────────┬───────────┐  │
│  │           │           │           │           │           │  │
│  ▼           ▼           ▼           ▼           ▼           ▼  │
│  sensor_    rfid_       espnow_     local_      anomaly_    serial_│
│  manager.h  manager.h   comm.h      rules.h     detector.h  comm.h │
│  (pulses)   (RFID)      (ESP-NOW)   (leak)      (anomaly)   (USB) │
│  │           │           │           │           │           │  │
│  ▼           ▼           ▼           ▼           ▼           ▼  │
│  ┌───────────┬───────────┬───────────┬───────────┬───────────┐  │
│  │           │           │           │           │           │  │
│  ▼           ▼           ▼           ▼           ▼           ▼  │
│  wifi_      data_       led_        ntp_        ota_        —   │
│  manager.h  logger.h    indicator.h sync.h      updater.h       │
│  (WiFi)     (SPIFFS)    (LED)       (NTP)       (OTA)          │
│                                                                 │
└─────────────────────────────────────────────────────────────────┘
```

### Main ESP32 Modules (×1)

```
┌─────────────────────────────────────────────────────────────────┐
│  MAIN ESP32 MODULE STACK                                        │
│  ─────────────────────────────────────────────────────────────  │
│                                                                 │
│  ┌───────────────────────────────────────────────────────────┐  │
│  │  main-esp32.ino          Main sketch (setup + loop)       │  │
│  └───────────────────────┬───────────────────────────────────┘  │
│                          │                                      │
│  ┌───────────────────────▼───────────────────────────────────┐  │
│  │  config.h              All parameters (pins, thresholds)  │  │
│  └───────────────────────┬───────────────────────────────────┘  │
│                          │                                      │
│  ┌───────────┬───────────┼───────────┬───────────┬───────────┐  │
│  │           │           │           │           │           │  │
│  ▼           ▼           ▼           ▼           ▼           ▼  │
│  sensor_    espnow_     firebase_   relay_      leak_       anomaly_│
│  manager.h  receiver.h  client.h    controller.h detector.h  detector.h│
│  (pulses)   (ESP-NOW)   (Firebase)  (relays)    (leak)      (anomaly)│
│  │           │           │           │           │           │  │
│  ▼           ▼           ▼           ▼           ▼           ▼  │
│  ┌───────────┬───────────┬───────────┬───────────┬───────────┐  │
│  │           │           │           │           │           │  │
│  ▼           ▼           ▼           ▼           ▼           ▼  │
│  wifi_      data_       led_        ntp_        ota_        serial_│
│  manager.h  logger.h    indicator.h sync.h      updater.h   comm.h│
│  (WiFi)     (SPIFFS)    (LED)       (NTP)       (OTA)       (USB)│
│                                                                 │
└─────────────────────────────────────────────────────────────────┘
```

---

## 2. Room ESP32 Module Architecture

### 2.1 Module Dependency Graph

```
┌─────────────────────────────────────────────────────────────────┐
│  ROOM ESP32: MODULE DEPENDENCIES                                │
│  ─────────────────────────────────────────────────────────────  │
│                                                                 │
│  config.h ◄────────────────── All modules read config.h        │
│      │                                                           │
│      ├──► sensor_manager.h   Reads flow sensor (GPIO 26)       │
│      │        │                                                   │
│      │        ├──► flow_rate, pulses, volume                    │
│      │        │                                                   │
│      │        ▼                                                   │
│      ├──► local_rules.h      Leak detection (6 rules)          │
│      │        │                                                   │
│      │        ├──► leak_alert, leak_flags                       │
│      │        ├──► controls: PIN_SSR, PIN_RELAY                 │
│      │        │                                                   │
│      │        ▼                                                   │
│      ├──► anomaly_detector.h Anomaly detection (3 methods)     │
│      │        │                                                   │
│      │        ├──► anomaly_flags, zscore, spike, burst          │
│      │        │                                                   │
│      │        ▼                                                   │
│      ├──► espnow_comm.h      ESP-NOW transmitter               │
│      │        │                                                   │
│      │        ├──► sends: sensor + leak + anomaly data          │
│      │        │   to main ESP32                                 │
│      │        │                                                   │
│      │        ▼                                                   │
│      ├──► rfid_manager.h     MFRC522 RFID reader               │
│      │        │                                                   │
│      │        ├──► card_uid, session_active                     │
│      │        │                                                   │
│      │        ▼                                                   │
│      ├──► serial_comm.h      USB Serial output (debug)         │
│      │        │                                                   │
│      │        ├──► JSON frames to Serial Monitor                │
│      │        │                                                   │
│      │        ▼                                                   │
│      ├──► data_logger.h      SPIFFS fallback logging           │
│      │        │                                                   │
│      │        ├──► logs alerts when WiFi/ESP-NOW unavailable    │
│      │        │                                                   │
│      │        ▼                                                   │
│      ├──► led_indicator.h    LED status patterns               │
│      │        │                                                   │
│      │        ├──► green=safe, yellow=warning, red=leak        │
│      │        │                                                   │
│      │        ▼                                                   │
│      ├──► wifi_manager.h     WiFi (for OTA + NTP only)         │
│      │        │                                                   │
│      │        ├──► connects to WiFi for OTA updates             │
│      │        │                                                   │
│      │        ▼                                                   │
│      ├──► ntp_sync.h         NTP time sync                     │
│      │        │                                                   │
│      │        ├──► timestamps for alerts                        │
│      │        │                                                   │
│      │        ▼                                                   │
│      └──► ota_updater.h      OTA firmware updates              │
│                                                                 │
└─────────────────────────────────────────────────────────────────┘
```

### 2.2 Data Flow Through Modules

```
┌─────────────────────────────────────────────────────────────────┐
│  ROOM ESP32: DATA FLOW PER CYCLE (~100ms)                      │
│  ─────────────────────────────────────────────────────────────  │
│                                                                 │
│  T=0ms     sensor_manager.readAll()                            │
│            │  Reads ISR pulse counter (atomic)                  │
│            │  Calculates: flowRate, volume, pulses              │
│            │  Output: float flowRate                            │
│            ▼                                                    │
│  T=5ms     rfid_manager.poll()                                 │
│            │  Checks MFRC522 for card tap                       │
│            │  Validates card UID against registered list        │
│            │  Manages session start/end                         │
│            │  Output: bool sessionActive, char cardUid[]        │
│            ▼                                                    │
│  T=10ms    local_rules.checkAll(flowRate, sessionActive, ...)  │
│            │  Runs Rules 1-6                                    │
│            │  Checks debounce timers                            │
│            │  Controls SSR + Solenoid if leak detected          │
│            │  Output: bool leakAlert, uint8_t leakFlags         │
│            ▼                                                    │
│  T=15ms    anomaly_detector.checkAll(flowRate, ...)            │
│            │  Runs rate-of-change, baseline, burst detection    │
│            │  Updates baseline tracker                          │
│            │  Output: bool spike, bool baseline_dev, bool burst │
│            ▼                                                    │
│  T=20ms    [IF send interval elapsed: every 5 sec]             │
│            espnow_comm.send(payload)                            │
│            │  Builds JSON payload:                              │
│            │  { room_id, pulses, flow_rate, volume,             │
│            │    leak_alert, leak_flags,                         │
│            │    anomaly_spike, anomaly_baseline, anomaly_burst }│
│            │  Sends via ESP-NOW to main ESP32                   │
│            ▼                                                    │
│  T=25ms    led_indicator.update()                               │
│            │  Sets LED pattern based on:                        │
│            │  - leakAlert → red flash                           │
│            │  - anomaly → yellow blink                          │
│            │  - normal → green solid                            │
│            ▼                                                    │
│  T=30ms    [IF USB Serial available]                           │
│            serial_comm.sendStatus()                             │
│            │  Outputs JSON to Serial Monitor (921600 baud)      │
│            ▼                                                    │
│  T=50ms    [IF alert logged]                                   │
│            data_logger.logAlert(alertType, roomId)              │
│            │  Writes to SPIFFS if ESP-NOW/ WiFi unavailable     │
│            ▼                                                    │
│  T=100ms   delay(100) — end of cycle                           │
│                                                                 │
└─────────────────────────────────────────────────────────────────┘
```

---

## 3. Main ESP32 Module Architecture

### 3.1 Module Dependency Graph

```
┌─────────────────────────────────────────────────────────────────┐
│  MAIN ESP32: MODULE DEPENDENCIES                                │
│  ─────────────────────────────────────────────────────────────  │
│                                                                 │
│  config.h ◄────────────────── All modules read config.h        │
│      │                                                           │
│      ├──► sensor_manager.h   Reads calibrated flow sensor      │
│      │        │              (GPIO 34)                          │
│      │        ├──► inlet_flow_rate, inlet_volume                │
│      │        │                                                   │
│      ▼                                                           │
│      ├──► espnow_receiver.h  ESP-NOW receiver                  │
│      │        │                                                   │
│      │        ├──► receives: room data from 3 room ESP32s      │
│      │        ├──► output: RoomData rooms[3]                    │
│      │        │   (pulses, flow_rate, volume,                   │
│      │        │    leak_alert, leak_flags,                      │
│      │        │    anomaly_spike, anomaly_baseline, anomaly_burst)│
│      │        │                                                   │
│      ▼                                                           │
│      ├──► leak_detector.h    Aggregated leak detection         │
│      │        │                                                   │
│      │        ├──► mass_balance check (inlet vs rooms)          │
│      │        ├──► post-shutoff verification                    │
│      │        ├──► intermittent leak detection                  │
│      │        ├──► sensor disagreement check                    │
│      │        ├──► output: global_leak_flag, severity           │
│      │        │                                                   │
│      ▼                                                           │
│      ├──► anomaly_detector.h Cross-room anomaly detection      │
│      │        │                                                   │
│      │        ├──► mass balance anomaly                         │
│      │        ├──► time-pattern analysis                        │
│      │        ├──► multi-room correlation                       │
│      │        ├──► trend detection (daily baselines)            │
│      │        ├──► output: global_anomaly_flag, anomaly_data    │
│      │        │                                                   │
│      ▼                                                           │
│      ├──► relay_controller.h Solenoid valve control            │
│      │        │                                                   │
│      │        ├──► controls 2CH relay (GPIO 19, GPIO 18)       │
│      │        ├──► shutoff solenoid 1, solenoid 2               │
│      │        ├──► verify shutoff (read flow after OFF)         │
│      │        ├──► output: solenoid1_on, solenoid2_on           │
│      │        │                                                   │
│      ▼                                                           │
│      ├──► firebase_client.h  Firebase RTDB + Auth              │
│      │        │                                                   │
│      │        ├──► push: room data, anomaly, alerts             │
│      │        ├──► pull: config overrides from dashboard        │
│      │        ├──► stream: real-time commands from dashboard    │
│      │        ├──► output: config updates, remote commands      │
│      │        │                                                   │
│      ▼                                                           │
│      ├──► serial_comm.h      USB Serial output (debug)         │
│      ├──► data_logger.h      SPIFFS fallback logging           │
│      ├──► led_indicator.h    LED status patterns               │
│      ├──► wifi_manager.h     WiFi connect + reconnect          │
│      ├──► ntp_sync.h         NTP time sync                     │
│      └──► ota_updater.h      OTA firmware updates              │
│                                                                 │
└─────────────────────────────────────────────────────────────────┘
```

### 3.2 Data Flow Per Cycle

```
┌─────────────────────────────────────────────────────────────────┐
│  MAIN ESP32: DATA FLOW PER CYCLE (~100ms)                      │
│  ─────────────────────────────────────────────────────────────  │
│                                                                 │
│  T=0ms     sensor_manager.readAll()                            │
│            │  Reads calibrated flow sensor (GPIO 34)            │
│            │  Output: float inlet_flow_rate, float inlet_volume │
│            ▼                                                    │
│  T=5ms     espnow_receiver.poll()                              │
│            │  Checks for incoming ESP-NOW packets               │
│            │  Updates RoomData rooms[3] with latest data        │
│            │  Output: rooms[0..2] with full payloads            │
│            ▼                                                    │
│  T=10ms    [IF send interval elapsed: every 5 sec]             │
│            │                                                    │
│            ├──► leak_detector.checkAll(rooms, inlet, ...)      │
│            │        │                                           │
│            │        ├── Mass balance: inlet vs sum(rooms)      │
│            │        ├── Post-shutoff: flow after solenoid OFF  │
│            │        ├── Intermittent: leak count per room      │
│            │        ├── Sensor disagreement: room vs main      │
│            │        │                                           │
│            │        ▼                                           │
│            │    global_leak_flag, severity, leak_details       │
│            │                                                    │
│            ├──► anomaly_detector.checkAll(rooms, inlet, ...)   │
│            │        │                                           │
│            │        ├── Cross-room: 2+ rooms anomaly = flag   │
│            │        ├── Time-pattern: night/weekend usage      │
│            │        ├── Trend: daily volume vs 7-day avg      │
│            │        │                                           │
│            │        ▼                                           │
│            │    global_anomaly_flag, anomaly_details           │
│            │                                                    │
│            ├──► relay_controller.executeResponse(severity)     │
│            │        │                                           │
│            │        ├── EMERGENCY → shutoff both solenoids    │
│            │        ├── CRITICAL → shutoff + retry            │
│            │        ├── WARNING → log only                    │
│            │        │                                           │
│            │        ▼                                           │
│            │    solenoid1_on, solenoid2_on updated             │
│            │                                                    │
│            └──► firebase_client.pushData(rooms, anomaly, ...)  │
│                     │                                           │
│                     ├── Write /rooms/{id}/data                 │
│                     ├── Write /rooms/{id}/anomaly              │
│                     ├── Write /alerts/active/ (if alert)       │
│                     ├── Write /anomaly/global                  │
│                     │                                           │
│                     ▼                                           │
│                 Firebase RTDB updated                          │
│                                                                 │
│  T=50ms    firebase_client.stream()                            │
│            │  Check for incoming commands from dashboard        │
│            │  (remote shutoff, config update, recalibrate)     │
│            ▼                                                    │
│  T=60ms    led_indicator.update()                               │
│  T=70ms    serial_comm.sendStatus()                             │
│  T=100ms   delay(100) — end of cycle                           │
│                                                                 │
└─────────────────────────────────────────────────────────────────┘
```

---

## 4. Module Responsibilities Matrix

### 4.1 Room ESP32 Modules

| Module | Runs | Input | Output | Detection Role |
|---|---|---|---|---|
| `sensor_manager.h` | Every cycle | GPIO 26 pulses | flowRate, volume, pulses | Provides raw data |
| `rfid_manager.h` | Every cycle | MFRC522 SPI | sessionActive, cardUid | Context for leak rules |
| `local_rules.h` | Every cycle | flowRate, sessionActive, solenoidOn | leakAlert, leakFlags | **Core leak detection** |
| `anomaly_detector.h` | Every cycle | flowRate, flowRate_prev | spike, baseline_dev, burst | **Core anomaly detection** |
| `espnow_comm.h` | Every 5 sec | All above outputs | ESP-NOW packet | Transmits to main |
| `serial_comm.h` | On interval | All above outputs | JSON to Serial | Debug output |
| `data_logger.h` | On alert | Alert data | SPIFFS entry | Offline fallback |
| `led_indicator.h` | Every cycle | leakAlert, anomalyFlag | LED pattern | Visual status |

### 4.2 Main ESP32 Modules

| Module | Runs | Input | Output | Detection Role |
|---|---|---|---|---|
| `sensor_manager.h` | Every cycle | GPIO 34 pulses | inlet_flow_rate, inlet_volume | Calibrated metering |
| `espnow_receiver.h` | Every cycle | ESP-NOW packets | rooms[3] data | Aggregates room data |
| `leak_detector.h` | Every 5 sec | rooms[], inlet_volume | global_leak, severity | **Cross-room leak detection** |
| `anomaly_detector.h` | Every 5 sec | rooms[], inlet_volume | global_anomaly, anomaly_data | **Cross-room anomaly detection** |
| `relay_controller.h` | On command | severity, leakFlags | solenoid1_on, solenoid2_on | **Emergency shutoff execution** |
| `firebase_client.h` | Every 5 sec | All above outputs | Firebase RTDB writes | Cloud sync + dashboard |
| `firebase_client.h` | Streaming | Firebase commands | config updates, remote cmds | Dashboard → ESP32 |
| `serial_comm.h` | On interval | All above outputs | JSON to Serial | Debug output |

---

## 5. Data Flow: Sensor → Detection → Alert → Firebase

### 5.1 Complete Pipeline

```
┌─────────────────────────────────────────────────────────────────┐
│                    COMPLETE DATA PIPELINE                       │
│  ─────────────────────────────────────────────────────────────  │
│                                                                 │
│  PHYSICAL LAYER                                                 │
│  ┌───────────────────────────────────────────────────────────┐  │
│  │  Water flows through YF-S201 sensor                      │  │
│  │  Hall effect generates pulses (GPIO interrupt)            │  │
│  │  ~450 pulses per liter                                    │  │
│  └───────────────────────┬───────────────────────────────────┘  │
│                          │                                      │
│  FIRMWARE LAYER (Room ESP32)                                    │
│  ┌───────────────────────▼───────────────────────────────────┐  │
│  │  sensor_manager: ISR counts pulses → flowRate (L/min)     │  │
│  │  rfid_manager: reads card → sessionActive                 │  │
│  │  local_rules: applies 6 rules → leakAlert + leakFlags     │  │
│  │  anomaly_detector: z-score, spike, burst → anomalyFlags   │  │
│  └───────────────────────┬───────────────────────────────────┘  │
│                          │                                      │
│  WIRELESS LAYER                                                  │
│  ┌───────────────────────▼───────────────────────────────────┐  │
│  │  espnow_comm: sends JSON payload via ESP-NOW              │  │
│  │  { room_id, pulses, flow_rate, volume,                    │  │
│  │    leak_alert, leak_flags,                                │  │
│  │    anomaly_spike, anomaly_baseline, anomaly_burst }       │  │
│  │  Frequency: every 5 seconds                               │  │
│  └───────────────────────┬───────────────────────────────────┘  │
│                          │                                      │
│  AGGREGATION LAYER (Main ESP32)                                 │
│  ┌───────────────────────▼───────────────────────────────────┐  │
│  │  espnow_receiver: collects data from 3 rooms              │  │
│  │  leak_detector: mass balance, post-shutoff, intermittent  │  │
│  │  anomaly_detector: cross-room, time-pattern, trend        │  │
│  │  relay_controller: execute shutoff if severity >= CRITICAL│  │
│  └───────────────────────┬───────────────────────────────────┘  │
│                          │                                      │
│  CLOUD LAYER                                                     │
│  ┌───────────────────────▼───────────────────────────────────┐  │
│  │  firebase_client: pushes to Firebase RTDB via WiFi        │  │
│  │  /rooms/{id}/data      — sensor readings                  │  │
│  │  /rooms/{id}/anomaly   — anomaly flags + scores           │  │
│  │  /alerts/active/{id}   — active leak/anomaly alerts       │  │
│  │  /anomaly/global       — cross-room anomaly data          │  │
│  │  /baselines/           — learned patterns                 │  │
│  └───────────────────────┬───────────────────────────────────┘  │
│                          │                                      │
│  DASHBOARD LAYER                                                │
│  ┌───────────────────────▼───────────────────────────────────┐  │
│  │  Next.js on Vercel                                       │  │
│  │  Firebase onValue() listener — real-time sync             │  │
│  │  Renders: room cards, flow charts, alert feed, anomaly    │  │
│  │  gauge, trend analysis, threshold config                  │  │
│  └───────────────────────────────────────────────────────────┘  │
│                                                                 │
└─────────────────────────────────────────────────────────────────┘
```

### 5.2 Latency Budget

| Stage | Latency | Notes |
|---|---|---|
| Sensor pulse → ISR count | < 1ms | Hardware interrupt |
| ISR count → flowRate calc | < 5ms | Per cycle |
| Leak rule evaluation | < 10ms | 6 rules × simple comparisons |
| Anomaly detection | < 10ms | Z-score + rate-of-change |
| ESP-NOW transmit | < 50ms | Wireless, best effort |
| Main ESP32 aggregation | < 100ms | Per 5-sec cycle |
| Firebase push (WiFi) | 100–500ms | Depends on network |
| Dashboard render | < 100ms | Firebase onValue callback |
| **Total (sensor → dashboard)** | **< 1 second** | End-to-end |

---

## 6. ESP-NOW Protocol (Room → Main)

### 6.1 Packet Structure

```cpp
// Room → Main ESP32 (every 5 sec)
struct RoomPayload {
    uint8_t  room_id;              // 1, 2, or 3
    uint32_t ts;                   // Timestamp (millis or NTP)
    uint32_t pulses;               // Pulse count this interval
    float    flow_rate_lpm;        // Current flow rate (L/min)
    uint32_t volume_ml;            // Cumulative volume (ml)
    bool     leak_alert;           // Any leak rule triggered
    uint8_t  leak_flags;           // Bitmask: rules 1-6
    bool     anomaly_spike;        // Rate-of-change spike
    bool     anomaly_baseline;     // Z-score > 3.0
    bool     anomaly_burst;        // Short burst detected
    uint8_t  anomaly_flags;        // Bitmask: spike|baseline|burst
    uint8_t  session_active;       // RFID session state
    uint8_t  solenoid_on;          // Solenoid valve state
    uint8_t  reserved[3];          // Future use / alignment
};
// Total: ~40 bytes (well within ESP-NOW 250-byte limit)
```
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

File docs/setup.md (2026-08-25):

# Setup Guide — Step-by-Step from Zero to Working System

> **Target audience:** College students / researchers building a water monitoring project
> **Estimated time:** 2–3 weeks (part-time)
> **Prerequisites:** Basic electronics knowledge, basic programming (C++ helpful but not required)

---

## Table of Contents

1. [Phase 1: Parts & Tools](#phase-1-parts--tools)
2. [Phase 2: Software Installation](#phase-2-software-installation)
3. [Phase 3: Waterline (Plumbing) Setup](#phase-3-waterline-plumbing-setup)
4. [Phase 4: Hardware Wiring](#phase-4-hardware-wiring)
5. [Phase 5: ESP32 Firmware Upload](#phase-5-esp32-firmware-upload)
6. [Phase 6: Sensor Calibration](#phase-6-sensor-calibration)
7. [Phase 7: Firebase + Next.js Setup](#phase-7-firebase--nextjs-setup)
8. [Phase 8: Testing the Full System](#phase-8-testing-the-full-system)
9. [Phase 9: Enclosure & Deployment](#phase-9-enclosure--deployment)

---

## Phase 1: Parts & Tools
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

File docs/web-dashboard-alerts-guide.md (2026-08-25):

# Web Dashboard Alerts Guide — TapFlow

> **Purpose:** Next.js dashboard implementation for real-time anomaly detection + leak detection visualization, alert management, and threshold configuration.
> **Builds on:** [anomaly-detection-guide.md](./anomaly-detection-guide.md), [leak-detection-advanced-guide.md](./leak-detection-advanced-guide.md), [module-integration-guide.md](./module-integration-guide.md)

---
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

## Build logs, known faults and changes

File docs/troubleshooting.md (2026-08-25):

# Troubleshooting Guide

> Complete guide for diagnosing and fixing issues with the Water Meter + Leak Detection system (ESP32 → ESP-NOW → Firebase → Next.js).

---

## 1. ESP32 Hardware Issues

### No Power / No Lights

| Cause | Check | Fix |
|---|---|-----|
| USB cable is charge-only | Try a known good data cable | Use cable rated for data transfer |
| Wrong USB port | Device Manager → Ports | Use USB 2.0 or 3.0 port directly on computer |
| ESP32 damaged | Check 3.3V pin with multimeter | Replace ESP32 |
| Expansion board short | Check for solder bridges | Remove expansion board, test ESP32 alone |

### No Serial Output

| Cause | Check | Fix |
|---|---|-----|
| Wrong COM port | Device Manager → Ports | Select correct COM port |
| Baud rate mismatch | Set to 921600 | In Serial Monitor, set baud to 921600 |
| Driver missing | Device Manager → yellow exclamation | Install [CP210x](https://www.silabs.com/developers/usb-to-uart-bridge-vcp-drivers) or CH340 driver |
| Board not in flash mode | Hold BOOT → press EN → release BOOT | Hold BOOT → press EN → release BOOT → Upload |

### ESP32 Crashes / Reboot Loops

```cpp
// Add this to setup() to diagnose
Serial.println("Free heap: " + String(ESP.getFreeHeap()));
Serial.println("Reset reason: " + String(esp_reset_reason()));
```

| Symptom | Cause | Fix |
|---|---|-----|
| Brownout detector triggered | Unstable power supply | Use ≥2A adapter, add 1000µF capacitor |
| Guru Meditation Error | Stack overflow / memory issue | Reduce buffer sizes, add `yield()` in loops |
| Watchdog reset | Task blocking > 5 seconds | Add `delay(0)` or `yield()` |
| WiFi disconnect loop | Weak signal | Move router closer, add antenna |
| Flash corruption | Power loss during write | Use `SPIFFS.format()` in setup |

---

## 2. Flow Sensor Issues

### No Pulse Reading

| Cause | Check | Fix |
|---|---|-----|
| Wrong GPIO pin | Verify `SENSOR_PINS[]` in config.h | Match config to actual wiring |
| Loose connection | Inspect connections | Push firmly or re-seat |
| Sensor not powered | Measure VCC pin | Should be 4.5V–5V |
| Arrow wrong direction | Arrow on sensor body | Install with flow direction |
| Air trapped | Bubbles in sensor chamber | Tap sensor, purge air |
| Debounce too high | Pulses < 5ms apart missed | Reduce `DEBOUNCE_MS` to 3 |
| Flow too slow | Minimum ~0.5 L/min | Increase flow rate |

**Quick test:** Connect sensor OUT directly to 3.3V momentarily. If Serial Monitor shows pulses, ESP32 is OK — problem is sensor or water flow.

### Wrong Volume Readings

| Symptom | Likely K-factor | Fix |
|---|---|-----|
| Reading too high (overcounts) | PPL too low | Increase `PULSE_PER_LITER` |
| Reading too low (undercounts) | PPL too high | Decrease `PULSE_PER_LITER` |
| Inconsistent readings | Air / turbulent flow | Add straight pipe before sensor |
| Drifts over time | Temperature change | Re-calibrate seasonally |

### Fixture Balance Error

```
Inlet balance = Inlet volume - (Fixture 1 + 2 + 3)
Normal: balance < 10% of inlet
```

| Balance | Meaning | Action |
|---|---|---|
| < 10% | Normal | No action needed |
| 10–20% | Leak suspected | Investigate fixtures |
| > 20% | Hidden leak or sensor fault | Check all connections |

---

## 3. USB Serial Issues

### ESP32 Not Detected on Computer

```bash
# Check if device appears
ls /dev/ttyUSB*
ls /dev/ttyACM*

# Check kernel messages
dmesg | grep -i usb
```

| Issue | Fix |
|---|-----|
| No `/dev/ttyUSB*` | Use data cable, not charge-only |
| Permission denied | `sudo usermod -a -G dialout $USER && newgrp dialout` |
| Wrong VID:PID | Check `lsusb` — should show `10c4:ea60` (CP2102) or `1a86:7523` (CH340) |
| Multiple devices | Use udev rule for persistent `/dev/ttyESP32` symlink |

### Serial Connection Drops

```python
# Test connection
python3 -c "
from serial_port import find_esp32_port, get_serial_connection
port = find_esp32_port()
print(f'Port: {port}')
ser = get_serial_connection()
print('Connected!')
for _ in range(3):
    print(ser.readline().decode().strip())
"
```

| Symptom | Cause | Fix |
|---|---|-----|
| Random disconnects | Loose USB cable | Secure cable, use strain relief |
| `SerialException` on read | ESP32 reset | Handle reconnect in reader (auto-reconnect built-in) |
| Garbage characters | Baud mismatch | Both sides must use **921600** |
| Partial JSON lines | Buffer fragmentation | Reader accumulates until newline (built-in) |

### udev Rule Not Working

```bash
# Check rule
cat /etc/udev/rules.d/99-esp32.rules

# Test rule
udevadm test /dev/ttyUSB0

# Reload
sudo udevadm control --reload-rules
sudo udevadm trigger

# Verify symlink
ls -la /dev/ttyESP32
```

---

## 4. Dashboard / Firebase Issues

| Cause | Check | Fix |
|---|---|-----|
| Vercel deployment failed | Check Vercel dashboard → Deployments | Redeploy from Git |
| Firebase config wrong | Check `.env.local` in Next.js project | Verify API key, database URL |
| Firebase Auth not enabled | Firebase Console → Authentication | Enable Email/Password + Google |
| RTDB rules blocking | Firebase Console → Realtime Database → Rules | Set read/write to true for testing |

---

## 5. Plumbing / Mechanical Issues

| Problem | Cause | Fix |
|---|---|-----|
| Water hammer | Fast valve closing | Install water hammer arrestor |
| Sensor not spinning | Debris in turbine | Remove and clean with soft brush |
| Check valve stuck | Debris or hard water | Disassemble and clean |
| Leaks at threads | Insufficient Teflon tape | Re-wrap with 3–5 turns PTFE tape |
| PPE joint leak | Insufficient heat fusion | Re-weld with PPR welding machine, ensure proper temperature (260°C) |

---

## 6. Diagnostic Commands (Serial Monitor)

Connect ESP32 via USB, open Serial Monitor at **921600 baud**, send:

| Command | Response | Use Case |
|---|---|---|
| `status` | All sensor readings + device state | Quick health check |
| `sensors` | Raw pulse counts per sensor | Debug ISR issues |
| `config` | Current configuration | Verify settings |
| `wifi` | WiFi status + IP + RSSI | Network troubleshooting |

| `calibrate` | Start calibration mode | For bucket test |
| `reset` | Reboot ESP32 | Quick restart |
| `format` | Format SPIFFS storage | Clear corrupted data |
| `heap` | Free heap memory | Check for memory leaks |
| `uptime` | Device uptime in seconds | Know when last rebooted |

---

## 7. Built-in LED Indicator Reference

| LED Pattern | Meaning |
|---|---|
| Solid green | Normal operation, all OK |
| Blink green (1s) | WiFi connecting |
| Blink blue (fast) | Transmitting serial data |
| Solid yellow | Minor leak detected (alert) |
| Solid red | Major leak detected (critical) |
| Red flash | Emergency — urgent action needed |
| Blink white (3x + pause) | Successful data send |
| Blink red (5x + pause) | Send failed / error |
| Off | Deep sleep or no power |

---

## 8. Checklist Before Panicking

- [ ] Is ESP32 getting power? (LED on?)
- [ ] Is USB cable a **data cable**? (not charge-only)
- [ ] Is Serial Monitor baud set to **921600**?
- [ ] Is the flow sensor arrow pointing **WITH** water flow?
- [ ] Are WiFi SSID and password correct?
- [ ] Is `PULSE_PER_LITER` calibrated for each sensor?

---

## 9. RFID Reader (MFRC522) Issues

### Card Not Detected

| Cause | Check | Fix |
|---|---|-----|
| Wrong SPI pins | Verify SDA→GPIO 5, SCK→18, MOSI→23, MISO→19, RST→27 | Match config.h to wiring |
| 3.3V not 5V | MFRC522 runs on 3.3V | Connect VCC to 3.3V, NOT 5V (will damage module) |
| Loose SPI wires | Reseat all 7 wires | Use shorter wires, check solder joints |
| Wrong card type | Card must be Mifare Classic 1K/4K | Check card type with RFID phone app |
| Antenna interference | Metal near reader | Mount reader away from metal surfaces |

### RFID Session Issues

| Symptom | Cause | Fix |
|---|---|-----|
| Card valid but no water | SSR not turning ON | Check PIN_SSR in config.h, verify SSR wiring |
| Water starts but stops immediately | Session timeout too short | Increase SESSION_TIMEOUT_MS in config.h |
| Can't end session | Card tap not detected | Ensure card tap triggers endSession() in firmware |
| Session stays on forever | Timeout not implemented | Add SESSION_TIMEOUT_MS logic to local_rules.h |

### Card Reads Unreliably

| Cause | Fix |
|---|-----|
| Distance too far | Tap card directly on reader (0–3 cm) |
| Multiple readers crosstalk | Shield readers with aluminum foil, increase distance between rooms |
| SPI clock too fast | Add `SPI.setFrequency(1000000)` in setup |

---

## 10. SSR + Solenoid Valve Issues

### Solenoid Does Not Open

| Cause | Check | Fix |
|---|---|-----|
| SSR not firing | Measure GPIO 25 with multimeter (should go HIGH) | Check firmware — PIN_SSR must be defined |
| SSR wiring wrong | Verify CTRL→GPIO 25, VCC→5V, GND→GND | Rewire per block-diagram.md |
| Solenoid polarity | DC solenoid has + and - | Swap wires if needed |
| Insufficient current | 40A SSR can handle it, but check 12V PSU | Ensure PSU provides ≥ 1A for solenoid |
| SSR defective | Test SSR with multimeter (output side) | Replace SSR |

### Solenoid Does Not Close (Shutoff Fails)

| Cause | Check | Fix |
|---|---|-----|
| SSR stuck ON | Measure GPIO 25 (should go LOW on leak) | Replace SSR — mechanical welding of contacts |
| Firmware bug | Check local leak rules trigger shutoff | Debug with Serial Monitor |
| NC solenoid wrong type | Must be NC (normally closed) | Replace with NC solenoid — NO type will fail-open |
| Power loss = open | NC solenoid closes on power loss (safe) | Verify solenoid is NC type |

### Solenoid Buzzing / Vibrating

| Cause | Fix |
|---|-----|
| SSR PWM not clean | Ensure GPIO is solid HIGH/LOW, not PWM |
| Low voltage | Check 12V PSU under load |
| Mechanical wear | Replace solenoid |

---

## 11. Getting Help

If stuck:
1. Check ESP32 Serial Monitor at 921600 baud
2. Run the diagnostic commands above
3. Open GitHub Issue with:
   - Serial Monitor output (last 50 lines)
   - Your `config.h` (remove WiFi passwords!)
   - Sensor types and plumbing layout

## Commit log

2026-08-25 refactor: multi-ESP32 architecture with ESP-NOW, RFID, SSR, Firebase + Next.js
    Replace single-ESP32 + RPi Flask architecture with:
    - 3 Room ESP32s (RFID + flow sensor + SSR + solenoid relay) → ESP-NOW → Main ESP32
    - Main ESP32 → WiFi → Firebase RTDB (via mobizt Firebase-ESP-Client)
    - Next.js on Vercel for web dashboard
    - Smart solenoid control (auto on/off to prevent overheating)
    - 6 leak detection rules (no-session flow, post-session flow, solenoid-off flow,
    continuous flow, drip, night flow)
    - Remove RPi, Flask, ML pipeline, touchscreen LCD, PVC pipe references
    🤖 Generated with Codebuff
    [isolation_forest_sample_dataset.csv, xgboost_sample_dataset.csv]
2026-08-25 refactor: centralized architecture — main ESP32 controls solenoids, rooms only RFID + leak detection
    - Main ESP32 now centralized with 2 relays (GPIO 25, 13) + 2 solenoid valves + calibrated flow sensor (GPIO 34)
    - Room ESP32s simplified to RFID + leak detection flow sensor only (no SSR, no relay)
    - Each ESP32 gets dedicated 12V PSU + buck converter (4 total)
    - Removed Fotek 40A SSR from BOM (relays replace SSR for solenoid control)
    - Updated Cirkit Designer wiring diagram link
    - Removed .ckt file, added *.ckt to .gitignore
    - Updated all docs: bom.md, README.md, block-diagram.md, system-architecture.md, stacks.md, setup.md
    🤖 Generated with Codebuff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
2026-08-25 chore: remove all Raspberry Pi references from docs
    RPi is no longer part of the architecture — ESP32 handles everything directly via WiFi + Firebase.
    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
2026-08-25 fix: update room ESP32 wiring with correct GPIO assignments
    Room ESP32 wiring corrected:
    - RFID RST: GPIO 27 → GPIO 21
    - SSR: GPIO 27 (room power — lights, fan, appliances)
    - Relay: GPIO 25 (solenoid valve control)
    - Power: Expansion board jack input → 12V PSU (6.5–16V)
    Updated mermaid diagrams to show SSR + relay per room.
    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
2026-08-25 fix: update main ESP32 wiring with 2CH relay and correct GPIO assignments
    Main ESP32 wiring corrected:
    - 2CH Relay: IN1→GPIO 19, IN2→GPIO 18 (controls 2 solenoid valves)
    - Flow Sensor: GPIO 34 (calibrated)
    - Reset Button: GPIO 27 (arcade button for WiFi creds reset)
    Updated mermaid diagrams and simplified wiring diagrams.
    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
2026-08-25 feat: add 12V DC power jack adapter to BOM
    Added DC power jack adapter (5.5×2.1mm, screw terminal) to convert
    PSU screw terminal output to barrel plug for ESP32 expansion board.
    Qty: 4 (1 per ESP32), Unit: ₱9, Total: ₱36.
    Updated power subtotal from ₱1,860 to ₱1,896.
    Updated cost summary totals.
    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
2026-08-25 chore: update BOM links to prioritize Makerlab Electronics
    All electronics items now link directly to Makerlab Electronics Shopee store.
    Hardware items (pipes, fittings, welding) link to high-rated hardware stores.
    Removed generic Shopee/Lazada links in favor of store-specific search links.
    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
2026-08-25 docs: add waterline structure (plumbing layout)
    Added waterline diagram showing:
    - Water tank (500-1000L) → 1\" pipe → reducer (1\"→1/2\")
    - Solenoid 1 → Flow sensor → Solenoid 2 (dual solenoid for redundancy)
    - T-connector → 1/2\" PPE pipe to each room
    Updated bom.md, block-diagram.md, and system-architecture.md.
    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
2026-08-25 docs: rewrite setup.md for beginner college students
    Complete rewrite of setup guide with:
    - Correct wiring diagrams (room ESP32: GPIO 5/18/19/21/23/25/26/27, main: GPIO 18/19/27/34)
    - Updated parts list matching current BOM
    - Added waterline structure (plumbing) section
    - Added power wiring section (12V PSU + DC jack adapter)
    - Added 2CH relay wiring for main ESP32
    - Added reset button wiring
    - Humanized language for college students
    - Correct phase ordering (plumbing before wiring)
    - Added troubleshooting table
    - Removed Python dependency (ESP32 talks directly to Firebase)
    - Updated config.h example with correct pin assignments
    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
2026-08-25 rename: WMLDAD → TapFlow
    Renamed project from WMLDAD to TapFlow:
    - Full name: TapFlow — RFID-Based Automatic Water and Electrical Line Control with Water Flow Anomaly Detection
    - Repo: qppd/tapflow (was qppd/wmldad)
    - Updated all docs: README.md, setup.md, bom.md, block-diagram.md, system-architecture.md
    - Updated device IDs: tapflow-room1, tapflow-main
    - Updated git clone URLs to tap-flow repo
    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
2026-08-25 fix: restore wmldad repo URLs (GitHub repo not yet renamed)
    Kept project name as TapFlow in titles, but repo clone URLs
    remain wmldad since the GitHub repo hasn't been renamed yet.
    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
2026-08-25 chore: remove model/ directory (3D files to be replaced later)
    Removed 15 files (14 PNG renders + 1 Fusion 360 .f3d file).
    Added model/ to .gitignore to prevent re-tracking.
    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
2026-08-25 chore: update repo URLs to tapflow
    GitHub repo renamed from wmldad to tapflow.
    Updated clone URLs in setup.md.
    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
2026-08-25 docs: add ChatGPT prompt for 3D model generation
    Comprehensive prompt with exact component dimensions, plumbing layout,
    electrical wiring routes, room mock-up sizes, and rendering requirements
    for generating an accurate 3D model of the TapFlow system.
    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
2026-08-25 chore: add chatgpt prompt to gitignore
    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
2026-08-25 docs: add anomaly + leak detection guides and update wiring diagram
    Add 4 comprehensive implementation guides for the detection system:
    - anomaly-detection-guide: algorithms (rate-of-change, z-score, burst, time-pattern, trend)
    - leak-detection-advanced-guide: 6 core rules + mass balance + pulse analysis
    - module-integration-guide: ESP32 module wiring, ESP-NOW protocol, Firebase integration
    - web-dashboard-alerts-guide: Next.js components, real-time alerts, threshold config
    Also update README with Phase 6 (detection system) and refresh wiring diagram image.
    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
2026-08-25 docs: align all diagrams, BOM, and pinouts to hybrid solenoid design
    The docs contradicted each other on who controls which solenoid valve
    and on room/main GPIO assignments. Standardize everything on the actual
    hybrid design: each room drives its own solenoid via a 1-ch relay
    (GPIO 25) plus Fotek SSR (GPIO 27), while the main ESP32 controls the
    2 centralized valves via one 2CH relay (IN1→19, IN2→18).
    - Fix Mermaid parse errors by quoting node labels containing parentheses
    - Add missing room SSR/solenoid nodes and main 2CH relay to diagrams
    - Correct stale firmware pins (SSR 25→27, relay 13→25, RFID RST 27→21)
    and add main-side pins (34, 19/18, reset button 27) to config.h
    - Add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
2026-09-04 feat: add updated TapFlow 3D models (Fusion 360 source + 8 renders)
    Add the new 3D enclosure models for TapFlow:
    - TapFlow.f3d — Fusion 360 source file (replaces old water-meter-fusion-360-file.f3d)
    - tapflow_view_1.png through tapflow_view_8.png — fixture assembly renders
    These replace the previously removed model/ directory (commit c4ceede)
    with renamed files matching the TapFlow project branding.
    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
    [TapFlow.f3d]
2026-09-04 docs: update 3D model references to match new TapFlow filenames
    - block-diagram.md: fix folder path (model/ → models/), rename files
    from water-meter-* to TapFlow.f3d and tapflow_view_1-8.png,
    remove 5 non-existent views (9–13)
    - README.md: add new "3D Models" section with clickable links to
    all 9 files in the models/ directory
    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
